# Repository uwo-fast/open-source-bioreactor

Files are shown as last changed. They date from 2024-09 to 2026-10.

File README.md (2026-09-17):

# open-source-bioreactor

Composable, modular, and extensible bioreactor design.

## status

> Under development, not yet ready for use.

- `scad/` - the OpenSCAD source, built around registered parameter sets for purchased parts and composable modules for printed ones. This replaced an earlier iteration that became unwieldy as the assembly grew; that tree was removed in `376c21f` and remains in the history.

## Documentation

- [`docs/build.md`](docs/build.md) — what to cut, print and tighten, and in what order
- [`docs/architecture.md`](docs/architecture.md) — who may hand a number to whom
- [`docs/design-conventions.md`](docs/design-conventions.md) — the rules the model is built to
- [`docs/agitation.md`](docs/agitation.md) — why the impeller is the size it is
- [`docs/ports-layout.md`](docs/ports-layout.md) — what sits at each port on the lid, and why
- [`docs/procurement.md`](docs/procurement.md) — how the bought parts were chosen
- [`docs/references.md`](docs/references.md) — the sources, and how far each one was actually read

## OpenSCAD Libraries

- [github.com/CameronBrooks11/bayonet-lock-scad](https://github.com/CameronBrooks11/bayonet-lock-scad)
- [github.com/thehans/FunctionalOpenSCAD](https://github.com/thehans/FunctionalOpenSCAD)
- [github.com/nophead/NopSCADlib](https://github.com/nophead/NopSCADlib)
- [github.com/rcolyer/threads-scad](https://github.com/rcolyer/threads-scad)

---

<div align="center">
  <p>
    
    
  </p>
</div>

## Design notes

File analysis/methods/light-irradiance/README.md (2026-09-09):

# Light irradiance — LED vs fluorescent

Spectrometer characterisation of the two lighting options considered for the
reactor, measured 2025-01. This is a **method**, not a culture run: it
characterises hardware and can be re-run against any future light source.

## Files

| Path | What |
| --- | --- |
| `raw/spectroscopy_data.csv` | Spectrometer export, untouched. Seven trials, 3,648 samples each. |
| `pipeline.py` | Rebuilds the per-condition splits and all four plots. |
| `derived/` | Regenerated, git-ignored. |
| `figures/` | Committed plots. |

Rebuild with:

```bash
just analysis-method light-irradiance    # or: python pipeline.py --verify
```

## Conditions

The raw export carries seven `(wavelength, irradiance)` column pairs under a
merged header row that names three conditions:

| Condition | Trials | Split file |
| --- | --- | --- |
| LED at 1 cm | 1 | `derived/spectroscopy_led1cm.csv` |
| Fluorescent, peak matched to the LED at 90 µW/cm²/nm | 3 | `derived/spectroscopy_flor90uWpeak.csv` |
| Fluorescent at 1 cm | 3 | `derived/spectroscopy_flor1cm.csv` |

Those three split files used to be committed as hand-made copies with no
script behind them. They are now regenerated: select the condition's columns,
then drop negative irradiance to NaN. Negative readings are instrument noise
below the detection floor — 363, 2,398 and 2,188 samples respectively, which
`--verify` reports.

Plots cover 300–800 nm, the range that matters for photosynthetically active
radiation.

## Reload

```python
import pandas as pd
led = pd.read_csv("derived/spectroscopy_led1cm.csv")
```

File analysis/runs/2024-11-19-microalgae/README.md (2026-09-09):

# Microalgae run — 2024-11-19

The first instrumented culture run on the v1 bioreactor. Temperature,
dissolved oxygen and pH were logged alongside the stirring motor and sample
pump for 8.9 days (2024-11-19 19:06 UTC → 2024-11-28 16:23 UTC).

This run predates the anolis telemetry stack; see
[`../2026-07-23-chlorella-ccpc90/`](../2026-07-23-chlorella-ccpc90/) for the
current export format.

> **Provenance warning.** Organism, strain, medium and vessel were never
> recorded for this run, and cannot now be recovered. Treat it as a
> commissioning shakedown of the logging chain rather than a characterised
> culture experiment.

## Files

| Path | What |
| --- | --- |
| `raw/microalgae_raw.csv` | The logger export, untouched. 28 MB, 152,712 rows. |
| `pipeline.py` | Rebuilds everything below from the raw file. |
| `derived/` | Regenerated, git-ignored. |
| `figures/` | Committed plots. |

Rebuild with:

```bash
just analysis-run 2024-11-19-microalgae     # or: python pipeline.py --verify
```

## Raw format: paired channels, independent clocks

The raw CSV is **not** a table. It is fourteen independent channels laid
side by side, each a `(time, value)` column pair with its **own clock and its
own length**, space-padded to the longest:

```
time,Air Cal,time,DO Cal,…,time,Thermo 1,time,Dissolved Oxygen,time,pH,time,Stirring,time,Pump 1,…
```

Row _i_ of `Thermo 1` and row _i_ of `pH` are **unrelated samples**. Channel
lengths differ accordingly:

| Channel | Samples | Kept as |
| --- | --- | --- |
| `Thermo 1` | 152,615 | `temperature` |
| `Dissolved Oxygen` | 152,624 | `dissolved oxygen` |
| `pH` | 152,661 | `pH` |
| `Stirring` | 152,688 | `stirring motor` |
| `Pump 1` | 152,712 | `sample pump` |

The other nine channels are one-shot calibration events (2 samples each) plus
the unused heating element and pH-control outputs, and are dropped.

## ⚠ The historical pipeline misaligned the channels

The originally committed `cleaned0/1/2` files were built by stacking the
channels **by row position**, which silently pairs samples taken minutes
apart. Measured skew relative to the `Thermo 1` clock:

| Channel | Median | 95th pct | Worst  |
| --- | --- | --- | --- |
| Dissolved Oxygen | −39 s  | +0.6 s | −475 s |
| pH | −154 s | −3.5 s | −513 s |
| Stirring | −258 s | −43 s | +948 s |
| Pump 1 | −338 s | −28 s | +948 s |

So in every previously published figure from this run, **pH lags its stated
timestamp by ~2.5 minutes on average and actuator state by ~5 minutes**, with
excursions to ±16 minutes. Slow trends are unaffected; anything that reads
short-term cause and effect between an actuator and a sensor is not.

`pipeline.py` therefore emits two frames:

- **`derived/tidy.csv`** — correct. Channels aligned onto the `Thermo 1` clock
  with a backward as-of join and a 30 s tolerance, so gaps stay NaN rather
  than being carried forward. **Use this.**
- **`derived/legacy_cleaned{0,1,2}.csv`** — bit-for-bit reconstructions of the
  files that used to be committed here, kept only so past figures remain
  auditable. Do not build new analysis on them.

Both apply the same two physical filters the original scripts did: temperature
outside 20–45 °C is sensor noise (there was no active heating or cooling), and
pH below 7 is the probe still settling at the start of the run.

## Reconstruction provenance

The step from `raw` to `cleaned0` was originally done by hand in a spreadsheet
and **no script for it was ever committed**. It has since been reverse-
engineered and is now `align_by_row_index()` in [`pipeline.py`](pipeline.py):
take channels by raw row position, set `time = round(Thermo 1 time)`, drop the
duplicated first scan, drop the final row, and uppercase the booleans.

`python pipeline.py --verify` checks the reconstruction against the sha256 of
each file as it was committed before the 2026-08 restructure:

| File | sha256 | Status |
| --- | --- | --- |
| `legacy_cleaned1.csv` | `0d2900e5…` | byte-identical |
| `legacy_cleaned2.csv` | `91ff8a32…` | byte-identical |
| `legacy_cleaned0.csv` | `b158e353…` | see below |

`cleaned0` as committed had sha256 `e64c807c…` and differs from the
reconstruction in **exactly one cell of 915,678**: the spreadsheet rounded a
temperature reading of `4.37069000783219e-19` to `4.37E-19`. The digest
recorded in `pipeline.py` is the faithful unrounded value. Nothing downstream
is affected — that sample fails the 20–45 °C filter either way, which is why
`cleaned1` and `cleaned2`, the files every published figure was actually built
from, still reproduce exactly.

## Reload

```python
import pandas as pd
tidy = pd.read_csv("derived/tidy.csv", parse_dates=["datetime"])
```

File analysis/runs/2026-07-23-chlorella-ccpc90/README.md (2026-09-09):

# Chlorella vulgaris (CCPC 90) photobioreactor run — telemetry export (2026-07)

Full telemetry export of the July 2026 bioreactor culture, pulled from the Pi's
InfluxDB just before the culture was evacuated and the bench sterilized.

## Culture

- **Organism:** _Chlorella vulgaris_, strain **CCPC 90**
- **Feed / medium:** 0.2 g/L Miracle-Gro in DI water (unbuffered)
- **Control:** impeller stirring only; **no active pH control** (dose pumps configured but disabled the entire run)
- **Vessel / stack:** bioreactor-v1 machine profile; anolis runtime `bioreactor-automation`, providers `bread0` (CRUMBS/I2C actuators) + `ezo0` (Atlas EZO pH/DO probes)

## Export provenance

- **Source:** Pi `anolis-f95d50b1` (129.100.228.70), InfluxDB org/bucket `anolis` (native `--with-observability`, 30-day retention)
- **Window:** `2026-07-23T02:10:05Z → 2026-07-31T18:05:05Z` (~8.7 days, full retained history of this culture)
- **Exported:** 2026-07-31 (~14:05 EDT) via **`anolis-telemetry-export` v0.1.1** (`POST /v1/exports/signals:query`, `resolution.mode=raw_event`, `format=csv`), run from source on the Pi.
- All timestamps are **UTC (RFC3339 Z)**. EDT = UTC−4.
- Per-export manifests (query params + sha256 content hash) are in `raw/manifests/`; `raw/export_index.tsv` maps each signal → export-id → manifest-hash → row count.

### Why per-`(device,signal)` queries (tool caveat)

`anolis-telemetry-export` v0.1.1 has two bugs in `raw_event` mode when a query
spans **multiple field types** (`value_double`/`value_int`/`value_bool`/`value_string`/`value_uint`):

1. **Leaked header rows** — a fresh CSV/NDJSON header is re-emitted at every field-type transition (≈17 junk rows per 15 min of mixed data). Present in **both** CSV and NDJSON (upstream of the formatter).
2. **Wrong `value_type`** — every row is labelled `bool` regardless of the real type.

**Workaround used here:** query one `(device_id, signal_id)` pair at a time — each is a single field type → a single Flux table → **0 leaked headers and correct `value_type`**, at full raw fidelity. Verified: 0 leaked header rows across all 29 files; each signal carries exactly one correct type. `downsampled` mode is also clean (single pivoted table) if a smaller file is ever wanted.

## Files

| Path | What |
| --- | --- |
| `raw/signals_raw_long.csv` | **Master dataset** — all 29 signals, raw events, time-sorted, long/tidy format. 587,061 rows. |
| `raw/manifests/<device>__<signal>.manifest.json` | Export manifest per signal (query window, selector, row count, content hash). |
| `raw/export_index.tsv` | device · signal · rows · leaked_hdr(=0) · export_id · manifest_hash. |
| `pipeline.py` | Rebuilds everything below from the master. |
| `derived/per_signal/<device>__<signal>.csv` | The master split one file per signal (handy for loading a single series). Git-ignored. |
| `derived/pivoted_1min.csv` | Sensors resampled onto a shared 1-minute grid. Git-ignored. |
| `figures/` | Committed plots. |

`per_signal/` used to be committed next to the master, which stored all
587,061 rows twice. It is now regenerated:

```bash
just analysis-run 2026-07-23-chlorella-ccpc90    # or: python pipeline.py --verify
```

`--verify` cross-checks every regenerated split against the row counts in
`raw/export_index.tsv`; the splits come back byte-identical to the original
export.

### Schema (`raw/signals_raw_long.csv`)

```
timestamp,runtime_name,provider_id,device_id,signal_id,value,value_type,quality
```

Long format: one row per observed change (telemetry is emitted **on change**, not
at a fixed rate), so sampling cadence varies by signal. To analyze, pivot on
`timestamp` × `signal_id` (values don't share exact timestamps across signals —
resample/`merge_asof` in pandas).

### Signal glossary

| signal_id | device | meaning | type |
| --- | --- | --- | --- |
| `ph_value` | ph0 | pH | double |
| `do_mg_l` | do0 | dissolved O₂ (mg/L) | double |
| `do_saturation_pct` | do0 | dissolved O₂ (% sat) | double |
| `t1_c` | rlht0 | reactor temperature (°C) | double |
| `t2_c`, `setpoint1_c`, `setpoint2_c` | rlht0 | secondary temp / heater setpoints (unused this run) | double |
| `relay1_on`, `relay2_on` | rlht0 | heater relays (unused) | bool |
| `period1_ms`, `period2_ms` | rlht0 | relay PWM periods | uint64 |
| `motor2_target` / `motor2_value` | **dcmt0** | **impeller** commanded / echoed PWM (0–255) | int64  |
| `motor1_*` | dcmt0 | dcmt0 channel-1 (sampling; unused) | — |
| `motor*_*` | **dcmt1** | **dose pumps** (disabled entire run → flat) | — |
| `motor*_brake`, `estop` | dcmt0/dcmt1 | brake / e-stop state | bool |
| `mode` | dcmt0/dcmt1/rlht0 | device control mode (`open_loop` etc.) | string |

Row counts (raw events over the window): `ph_value` 204,189 · `t1_c` 181,988 ·
`do_saturation_pct` 97,898 · `do_mg_l` 91,316 · impeller `motor2_*` (dcmt0) ~764 ·
dose/other actuator + rlht static signals 204–755 each.

## Run timeline & caveats (read before analysis)

Full ops/dev detail: `anolis/working/incident-2026-07-24-impeller-failure.md`.

- **Impeller (dcmt0) failed 2026-07-23 19:46 EDT**, undetected ~22 h; recovered 07-24 ~20:19 EDT (board power-cycle + staged restart). No stirring/dosing in that gap → pH fell to ~3.9.
- **Base dose(s)** added manually (unbuffered medium, no pH-stat) → pH stepped back up; culture ran at pH ~8.3 thereafter.
- Two **unexplained reboots** (07-24 11:45, 07-28 23:14 EDT) — brief telemetry gaps.
- **Planned power outage 2026-07-30 18:00 → 07-31 ~06:15 EDT (~12 h):** hard power-off, ~12 h gap in the data. Over the dark/unstirred window the culture **respired** (DO 140 %→86 % sat, pH 8.12→~7.5). **⚠ Clock artifact:** the Pi has no RTC battery, so a short burst of post-boot IDLE data around 07-31 morning is mis-stamped **~22:00–23:00 UTC 2026-07-30** (fake-hwclock restored the poweroff time until NTP synced ~11:00 UTC). Treat the true run boundary as the power cut ~22:00 UTC 07-30 (18:00 EDT).
- Final **short stirred run** 07-31 ~17:22 EDT to capture recovery, then culture evacuated.
- **DO probe** reads supersaturated (>100 % sat) for most of the run — active photosynthesis, but calibration date unknown; treat absolute DO with caution, trends are reliable.

## Reload

```python
import pandas as pd
df = pd.read_csv("raw/signals_raw_long.csv", parse_dates=["timestamp"])
ph  = df[df.signal_id=="ph_value"][["timestamp","value"]]
do  = df[df.signal_id=="do_saturation_pct"][["timestamp","value"]]
tmp = df[df.signal_id=="t1_c"][["timestamp","value"]]
```

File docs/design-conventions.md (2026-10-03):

# Design conventions

Rules this model is built to. They were arrived at by getting them wrong first, so each one carries
the failure it exists to prevent. Anything contradicting them is a defect rather than a variation.

---

## The rim datum

**The lid is located by the glass rim.** Its gasket seats on the top of the glass and its plug
enters the mouth. The rim is fixed by the jar; the frame's top base is derived _below_ it.

**What the gasket seats ON is per jar, and only one of them is flat.** `jar_6p5gal_305x470` is
ground and presents a flat annulus. Every other jar is fire-polished and presents a CROWN — the
glass rolls over, and on two of them the roll stands proud of the wall as a bead. So there is no
land to inset a gasket into and none to bottom the flange on: the gasket covers the lip instead,
and what gets squeezed is the band the crown makes as it sinks in.

The consequence that matters: the **2.4 mm gap** between the top base's upper face and the lid
flange's underside is _required_, not slack to be removed. It is the clearance that lets the joint
bolts pull the lid down **into** the vessel rather than bottoming it on the frame. Every span
crossing the joint has to count it — bolt grips, nut placements, anything measured from one side to
the other.

Anything that seats the lid on the frame instead of the glass is wrong. This was mis-derived
backwards twice before it was written down.

**Frame coordinates.** The frame builds with z = 0 at its own floor, then draws its body offset by
`−base_floor_height`. Frame-local `total_height` = 349.75 is assembly z = 305, the rim. If those
look contradictory, the offset has been forgotten.

---

## One physical thing, one expression

The repo's recurring defect: one physical fact stated twice, in two places, which agree until one
moves. Every instance found this way was silent — the model built happily and the two numbers
simply diverged.

Real examples, each of which shipped:

- The **strip light** was selected twice — the assembly passed only its length while the frame read
  its own second selection. Changing the light resized the frame around a pocket that never moved.
- The **impeller ratio** multiplied the vessel's outer diameter where D/T means the bore, so the
  real ratio drifted with glass thickness rather than being held constant.
- The **cart** sized its envelope off the bare jar, so two bioreactors on a tier overlapped by
  17.4 mm and each passed through the rail above it.
- The **bearing's** allowance was applied twice — once folded into the registered diameter and again
  as the pocket allowance — leaving the pocket 0.8 mm oversize.
- The **eccentricity analysis** measured T as the outer diameter — the impeller-ratio defect above,
  recurring in a document after it had been fixed in the model, so the two disagreed about what T
  meant while sitting in one repository. Nothing could catch it: no geometry reads those numbers.
  It is the clearest case for the rule below that a document is the second expression, and the
  worse place for one.

The fix is always the same shape: one expression, read back by whoever needs it. Subassemblies
export accessors (`frame_outer_diameter()`, `head_gasket_factor()`) rather than have consumers
rebuild the value.

**Name the quantity, not a quantity that resembles it.** Three defects here came from names that
permitted two readings — outer diameter versus bore, motor speed versus output speed, screw centre
distance versus bolt circle. If a field could be read two ways, it eventually will be.

**Documents are the second expression.** The same defect appears in prose, and there it is worse:
the model cannot check a document, so a stale figure sits unchallenged until a reader trusts it.
Eight were found in one pass — a D/T cap the model had moved, a thermocouple nothing buys, a pump
delivery the model explicitly retracts in its own echo, a fenced echo quoting a number the model no
longer emits, and one document stating both that the baffle hangs its full length and that it has
never been lengthened.

Prefer quoting an accessor or an echo over restating its result. Where a figure must be written out,
**check it against the model rather than against another document** — several of these agreed with
each other and with nothing else.

**A corrected figure is replaced where it sits and recorded once in `decisions.md`.** The old
value is evidence of which assumption failed, so it goes under _Corrections_ there, with what made
it wrong. It does not stay inline: a superseded paragraph beside its replacement is a second
expression of the same fact, and the commit that made the correction already holds the diff.

---

## Three layers, and where a parameter lives

The model was built on two: things two components must agree on, which live in `bioreactor.scad`, and
a component's own preferences, which live in its own file. That is right as far as it goes, and it
misses a third kind, which surfaced when a build's choices had nowhere to be stated.

A **DESIGNATION** is a per-reactor choice: which registered jar, which motor, which probe in which
port, what fill fraction. It is not a preference — it is about _this_ build, not about the design —
and it is not classic coupling, because `bioreactor.scad` may never consume it. It is forced into the
entry file anyway, by a platform fact: a customizer parameter set can only assign parameters
declared in the file being rendered. See _What the customizer can and cannot carry_.

**Where a parameter lives.** It belongs in `bioreactor.scad` if any of these hold:

- two or more components must agree on it;
- `bioreactor.scad` itself consumes it in a derivation — `frame_wall_thickness` feeding
  `joint_outer_diameter`, the fill fraction feeding light selection, the shaft feeding the envelope;
- it is a designation, a per-reactor choice an operator states.

Everything else stays in the component that embodies it: allowances, wall thicknesses, land margins,
joint geometry, and the search that derives a designation left unstated.

**A designation travels as a NAME, never as a row.** A parameter set holds values, not references,
so a registered row cannot be named directly. The form is a string parameter resolved through that
registry's by-name lookup — `reactor_vessel_name` with `vessel_by_name()` is the pattern — with a
loud assert on a name nothing matches. `"auto"` means _derive it_.

That string is not the plausible number this document bans elsewhere. `undef` is unavailable here
(the customizer cannot see it) and a numeric sentinel would be exactly the plausible value that
propagates unnoticed into arithmetic. A string cannot: it is visible in the surface, it is carried,
and it is consumed by a mode branch that never multiplies it by anything.

**Only departures travel.** The build list packs only what a build actually states; anything left at
`"auto"` is omitted, so the component's own search remains the single expression of the default.
Nothing is ever declared live in two files with defaults kept in step by hand.

**A value read back out of a component is an argument whose default is that component's own.**
`function head_gasket_factor(sheet = lid_gasket_sheet)` — verified: a default argument resolves in
the file that defines the function, not the caller's, so one expression serves both the standalone
preview and the assembled build and the readback cannot disagree with the geometry it describes.

**Pinning does not switch the checks off, it inverts them.** A designated row runs the same fit
asserts the derived one would have, and the echo reports what was pinned _and what derivation would
have chosen_. A selection over a registry holding one row says so — "sole registered row,
fit-checked, not chosen" — rather than implying a choice was made.

---

## Purchased parts are registered rows that drive geometry

Every bought part is a row in `scad/purchased/`, and the geometry is cut from the row rather than
from numbers typed beside it. The hole is derived from the insert; the pocket from the bearing; the
gasket recess from the sheet's thickness.

The failure this prevents: a heat-set insert was once modelled from a library row that **was not a
purchasable part**, and the lid was printed for it. A registry row must describe something orderable,
and where a library already carries the real part (`BB608` is the 608 bearing actually bought) the
library row is used directly rather than copied.

**The contract every registry owes.** A rows list; a `*_name()` accessor; a part number where a
stable one exists, and `undef` with the reason where it does not; provenance travelling with each
value; and a `*_by_name()` lookup wherever the part is designatable. Data-only registries — rows
that carry numbers and draw nothing — are legitimate.

**Only REAL parts go in the swept list.** The list is what `check-echo` and the sweeps build
against, so what sits in it is a claim about hardware.

A **placeholder** — a row describing nothing anyone ever bought, like `generic_vessel` or a
`"generic"` probe with an empty part number — stays defined and out of the list. It is a shape, not
a product, and sweeping it makes "this builds" cover something nobody can buy.

A **discontinued or bundled** part is the opposite case and stays swept, with the deviation recorded
beside the list. The 36GP motor is no longer sold and is on the bench; the 12 V pump motor arrives
fitted to a pump head and has no part number of its own; both Atlas g1 probes are out of production
and still in use. Refusing to sweep those would stop checking hardware that exists, which is the
wrong way round — the point of the sweep is that real parts build.

**Designatable is not the same as purchased.** Every bought thing is a registered row; only the ones
an operator actually picks per reactor get a by-name lookup and a slot on the build surface. The
bearing, the heat-set inserts, the screws, the riser tube and its o-ring, the hose clamp are the
design's bill of materials — one expression each, not a menu.

---

## A number is a claim, and it carries how good a claim it is

Parametric CAD makes numbers adjustable. It does not make them _true_, and adjustable-but-unfounded
is the more dangerous state, because the model looks equally confident either way.

So every quantity in this model is one of four kinds, and which kind it is travels with it:

- **measured** — a source states it for this exact thing. `impeller_rushton_6`'s `Po 4.17 ± 0.14`.
- **correlated** — a published correlation computes it from this geometry, and can say where that
  geometry leaves the correlation's validity. `pbt_45_4` takes `Po` from Medek this way.
- **borrowed** — no source reaches this shape, so a nearby one's number stands in. Always echoed,
  never silent.
- **reasoned, not cited** — nothing in the literature held here supports it and the model needs a
  value anyway. Marked in the source with that exact phrase: the 0.5 D coverage floor, the baffle
  load, the mount slenderness limits, a diaphragm pump's curve taken as linear.

The failure this prevents is a borrowed number acquiring the authority of a measured one by sitting
in the same table. This model ran for months on `Po = 0.99` borrowed from a differently shaped
blade, annotated _conservative_; when the correlated value arrived it was **1.602**, so every power,
torque and dissipation figure had been 62 % optimistic while carrying a note saying the opposite.

**A registry row states what a source says, not what the design wants.** Where a source gives a
band, register the band. Where it gives nothing, register `undef` rather than a plausible number —
`undef` propagates and gets noticed, a plausible number does not.

---

## Report the departure, not just the number

Every correlation has a validity envelope, and this vessel is outside several of them. That is
normal for an instrument built from jars rather than from a vendor's catalogue. What is not
acceptable is _not knowing_ which ones.

So a check returns the **names** of what it violates, not a boolean:

```
impeller: pbt_45_4 Po 1.49248 and flow number 0.887217 from Medek's correlation
at 45 deg, extrapolated on ["T/D", "H/T"]
```

`stirred_tank_medek_departures()` returns a list because an extrapolation that is out on one count
is a different thing from one that is out on four, and a caller that only learns `false` cannot tell
them apart or say which to fix. Two of those three departures were removable — a fourth baffle
retired one, D/T would retire another — and that was only visible because they were named.

The same shape applies to bands the design is measured against: echo the value, the band, and the
source's own framing. Oldshue's `1–2 d` is an **allowance** — _"if the impeller can be placed…
these impellers offer"_ — so falling outside it is reported, not warned. And it is an allowance for
**fluidfoil** impellers, which this pitched blade is not, so the model says that too rather than
quietly grading one impeller class against another's guidance.

---

## Report a fit before you build the part

Register the geometry and its clearances, render, and read them — then draw. The reporting is
cheaper than the part and it is what catches the arithmetic.

The case that made this a rule: a sparge ring was planned at 1.4 D with **1.60 mm** of clearance to
the baffles. That figure was ring _centreline_ to baffle edge; the ring has a 6 mm section, so its
inner face is 3 mm further in and the true clearance is **−1.40 mm**. The ring overlapped. Nothing
about the plan looked wrong — the number was plausible, stated with a unit, and derived from real
dimensions. The assert caught it on the first render, before any geometry existed.

Working it properly then changed the design rather than the number: the radial band available is
6.95 mm, no round section of 6 mm fits it at any diameter, and the squeeze is entirely radial while
73 mm of height sits unused. The ring's section became 4 × 10 mm, which is also the reason it is
printed rather than bent — **a tube is round, and round does not fit**.

The 4 × 10 section was itself overtaken by a requirement the fit report could not see — a sealed
slot cannot be cleaned — and the sparger is a round tube now, placed by the mouth; see
`decisions.md`. The lesson stands: the fit report is what caught the −1.40 mm.

A model whose checks only run after the geometry exists will confirm whatever was built.

---

## The model should be able to catch its author

The point of the three sections above is not documentation. It is that the model disagrees with the
person editing it, in the same session, before anything is committed.

Every one of these was found by a check rather than by re-reading:

- `head()`'s `z = 0` is the lid's **outer** face, which the assembly seats `lid_flange_height` above
  the rim — so every vessel-referenced depth was **8 mm** out, and the drivetrain was drawn higher
  than the model reported it.
- The baffle area ratio compared plate **width** against a reference **area**, reporting 0.83 for
  baffling that was actually at 0.14.
- Medek's four-baffle condition was evaluated against `len(undef)`, because `_baffle_at` was
  assigned 230 lines below its first consumer — so it reported a departure on a lid that has four.
- A pitched blade run out to `radius` sweeps **past** the diameter its power number is defined on,
  because a tilted rectangle's outermost points are its corners. 1.5 % on diameter is 7 % on power.
- A round feed boss on the sparge ring was wider than the ring's own section and fouled the baffles
  and the jar's mouth simultaneously, at 0.29 and 0.26 mm.

None of these were subtle once seen and none were visible while writing the code that caused them.

**What this costs.** It is verbose, and it is only as good as the checks someone bothered to write —
a number can be wrong in a way nothing checks, and a reported band is not a promise the value is
right. `reasoned, not cited` is still a guess; it is only a _labelled_ guess. The claim here is
narrow: that labelling which numbers are weak, and naming which conditions are violated, converts a
class of silent drift into a line of render output.

---

## Asserts versus echoes

This reactor is a research instrument. A parameter outside the usual range may be exactly what
someone is studying, so the model reports rather than refuses.

- **Assert** only what is physically impossible or unbuildable — an impeller too wide to pass the
  vessel mouth, a pocket cut through into the culture, a nut deeper than the base it sits in.
- **And cited bands at the pressure boundary may assert**, which is a deliberate exception rather
  than a lapse. The three o-ring checks — riser stretch, plug gland fill, plug containment — guard
  the seal between the culture and the room, and they come from gland practice rather than from
  this project's judgement. A seal outside its band is nearer unbuildable than it is to a variation
  someone is studying. A limit that is `reasoned, not cited` does **not** get that authority: it
  echoes.
- **Echo** the value and the literature band it sits against, with a distinct warning line when it
  falls outside. The build continues.

### Dead versus weak asserts

- **Dead** — the expression cannot vary, so no input reaches the failure. Delete it; it reads as
  coverage while providing none.
- **Weak** — it varies, but only absurd inputs trip it. Cheap insurance, keep it.

**Deadness is tested by sweeping the assert's own driving parameter**, never a proxy. Sweeping the
vessel registry proves nothing about a guard driven by cord diameter. Two asserts were deleted this
way after proving algebraically that their terms cancel; one more was very nearly deleted on a
proxy sweep before the correct driver showed it firing.

An assert derived from the thing it checks can never fire. If the code just computed the
relationship, do not then assert it.

---

## Verifying a change

Two OpenSCAD behaviours govern how anything here is checked, and both are counter-intuitive:

**A failing assert still exits 0.** A failed CSG export returns success and writes a ~1 byte file.
Nothing may be gated on `$?` — `just check-scad` greps stderr for `ERROR` and uses file size as a
backstop. Before this was understood, every failing vessel in a six-vessel sweep looked like a pass.

**Mesh export is not reproducible; CSG export is.** The same file exported three times gave 29454,
29452 and 29456 facets at three different file sizes, while the distinct z-level set and the
bounding box were identical across all three and the CSG output hashed identically.

So:

- _valid_ evidence — CSG diffs, distinct z-levels, bounding boxes, per-feature coordinates
- _not evidence_ — facet counts, STL file size, STL hashes

This also rules out STL hashing as a regression check for any future export tooling.

**A CSG diff is blind to whatever the preview drops.** `head.scad` sets
`$bayonet_shell_only = $preview && fast_bayonet_preview`, which makes the bayonet library emit bare
shells and skip every pin, channel and notch. CSG export runs in preview, so a CSG comparison shows
those features as unchanged **whatever was done to them** — a change to the pin angles came back
byte-identical, twice, before this was understood.

So a CSG diff proves nothing about a feature the preview is suppressing. Either render the affected
part on its own, or pass `-D fast_bayonet_preview=false` and compare that. The general form: **check
what the flags were before trusting what the diff says**, because a diff of two things that were
never drawn is a clean diff.

**`WARNING` is evidence too.** OpenSCAD reports an undef reaching arithmetic as a warning, not an
error, and a parse error in a `use`d file shows up as nothing else at all — a missing comma between
two string literals silently stopped `head.scad` exporting any of its functions while the file still
rendered on its own, and ninety warnings rode along unnoticed because the gate only grepped `ERROR`.
`check-scad` now fails on either.

**`just check-scad`** evaluates every file in both directions: the ones meant to render standalone
must emit geometry, and every other file must emit **none** — a registry that draws its own example
draws it into every consumer, which has happened once already. A new entry file therefore fails
until it is listed, which is the point.

**Neither of those runs CGAL, so neither can see a broken solid.** `.csg` export is a dump of the
tree, not an evaluation of it, and a mesh export tessellates without being asked whether the result
closes. The impeller's blades were drawn TANGENT to the hub — 264 non-manifold edges — and every
check above passed on it, every render, every time. It was found by measuring the STL.
**`just check-mesh`** closes that: it renders to a mesh and fails on a defect count above zero, and
**`just export-parts`** applies the same test to every part on the print manifest, one at a time.

**A check must be run in the configuration that makes the part, not the one that makes the
picture.** Four entry files render an assembly by default, and `check-mesh` used to skip all four as
"slow" and invite you to run them before a print. Three of them cannot pass: `head.scad`'s printed
geometry alone IS a 2-manifold, and what breaks it is `render_seals`, `render_probes`, and the
bearing with its coupling — EPDM in its grooves, Atlas bodies in their collets, a bearing on the
shaft, every one of them already on `check-parts`' `not_printed` list. So the check failed on
vitamins the repo had declared are not printed, could never pass, and taught anyone who ran it to
ignore it. `support/electronics_stand.scad` was on that list too and is not even slow: 14 s as a picture,
and 4 s as the bracket it prints, which is a clean 2-manifold. It is checked now.

**A check that cannot pass is worse than no check**, because the next real failure reads as more of
the same noise.

**Check at the `$fn` the desk uses, not only the one CI pins.** `$fn` is dynamically scoped, and
2021.01 lets a `use`d module resolve it from its own file where newer builds pass the caller's — so
a module that divides by `$fn` is fine under one and produces `nan` under the other. Nobody sees it,
because a `nan` propagates into a comparison that is simply false. `check-scad` runs a second pass at
**`-D '$fn=0'`**, which is what an unset viewport actually is, and geometry derives its facet count
from `$fa`/`$fs` rather than reading `$fn` off the caller.

**A clash check on a stand-in shape proves only the stand-in.** The condenser coil's preview tube was
a horizontal disc swept round the helix, a 0.4 mm ribbon in section, and a collision test passed on
it that a round tube would have failed; the printed head then cracked where the real tube would not
bend. Draw what is checked from the part's real section, and prove the check can fail by moving the
thing it guards - half a pitch, a few degrees - and watching it report. And a fit is not the only
question for something bent or wound: it has to be formable, at a radius the material takes, in the
order the parts go together - and a part it is formed against has to be built to carry that, which
the head that cracked was not, since its job was to locate a finished coil.

---

## What the customizer can and cannot carry

Measured on **OpenSCAD 2021.01**, by rendering probes rather than by reading documentation. Every
rule in _Three layers_ rests on these, so a version bump re-runs them before anything else.

- **`-D` reaches a `use`d file's globals. `-p`/`-P` does not.** A parameter set assigns only
  parameters declared in the file being rendered; keys naming a `use`d file's globals do nothing,
  silently. This is the fact that forces designations into the entry file.
- **A parameter defaulting to `undef` is invisible to the customizer.** It has no inferable type, so
  no parameter set can assign it. Proved by giving one a numeric default, at which point the same
  set applied. This is why a designation defaults to `"auto"` and never to `undef`.
- **A flat vector is carryable, but only as a string holding a SCAD literal.** A native JSON array
  is ignored without warning; `"[\"x\",\"y\"]"` applies, and may change length. Anything
  generating a parameter set has to emit that form.
- **A nested table cannot be carried at all**, in either encoding. Port tables and registry rows
  stay in SCAD; only their names travel.
- **`-p` beats `-D` on the same key, silently.** Keep the two key sets disjoint.
- **Almost everything fails at exit 0** — a bad `-P` name, a missing file, an unknown key, an
  unparseable value. Detection is a stderr grep or a `jq` check, never `$?`.
- **`-o /dev/null` does not render at all** — it exits 1 on the missing suffix. A check written that
  way passes whatever it is pointed at, which is the shape of check this document warns about
  everywhere else. Export to a real file.
- **Dropdown annotations are comments**, so an option list cannot be generated at runtime. Where one
  mirrors a registry, both ends say so.

---

## Standalone previews

Each subassembly renders on its own. Those previews must **derive** what the assembly would hand
them rather than quote the resulting numbers — a preview that quotes a bolt circle keeps building
the old one after the real derivation moves, and a part exported from it will not fit.

What a preview may legitimately choose are the things the assembly chooses: the vessel, the light,
the wall thickness, the flange height. Everything downstream of those is derived.

**A subassembly keeps its own parameters as live standalone defaults.** Opening `head.scad` and
working on it directly is worth more than the purity of deleting them, and an assembled build
overrides them only through the departures it states. Where a preview must restate something the
assembly owns, the restatement carries the drift label — it is two expressions held in step by
discipline and by the echo, not by construction, and it should be visible as such rather than
quietly correct.

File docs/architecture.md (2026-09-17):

# Architecture

Where a number is allowed to come from. `design-conventions.md` says how a number is justified;
this says who may hand it to whom. It is normative: a file that breaks a rule here is a defect, and
the audit of which files do is in `TODO.md`, not here.

## The layers

```
bioreactor.scad        the build: designations resolved, coupling derived once, head + frame composed
  ├── head.scad        subassembly: takes its coupling as arguments, standalone defaults
  ├── frame.scad       subassembly, same contract
  │     ├── custom/    printed parts: arguments in, geometry out
  │     ├── purchased/ bought parts: registry rows, accessors, a drawing of the vitamin
  │     └── utils/     standards and laws: thread tables, gland ratios, physics, geometry helpers
support/               furniture around the reactor; may compose bioreactor.scad, nothing composes it
_shelf/  _archive/      off the tree; nothing on it imports them
```

| Layer | Holds | May import | May not |
| --- | --- | --- | --- |
| `bioreactor` | designations by name, the coupling, the composition | `use` head, frame; the registries it resolves from | derive a number a subassembly also derives |
| `head`, `frame` | own preferences as live defaults; parts composed | `use` custom, utils; registries, to resolve names | read the other's state; read `bioreactor.scad` |
| `custom` | one general-case part per file; optionally its own interface registry | `use` utils, another custom part; `include` its own registry | read a `purchased/` registry; know a reactor |
| `purchased` | a swept row list, a by-name lookup, accessors, a drawing | `use` its own drawing, utils | know what it is bought for |
| `utils` | a standard, a law, a geometry helper | `use` other utils | know a part |

`use` unless it says `include`. `include` hands over every global of the included file, which is
the coupling this document exists to stop, so it is reserved for a file taking its own data: a
subassembly including the registries it resolves designations from, `bayonet_port.scad` including
`bayonet_interfaces.scad`.

## The rules

1. **Decisions flow down; interfaces are read back.** A module takes what it consumes as an
   argument. A composer may read a subassembly's accessor (`frame_outer_diameter()`,
   `head_gasket_factor()`) rather than rebuild the value. Nobody reads a global another file set,
   and no file reaches into a sibling's state. The one sideways read is `head.scad`'s standalone
   preview using `frame.scad` to derive the joint; it is preview-only and stays.

2. **A designation is resolved where the choice is owned.** `bioreactor.scad` resolves what a build
   states, by name through the registry's `*_by_name()`; a subassembly resolves its own `"auto"`.
   Geometry never browses a registry to decide what it wants. This is why a subassembly may include
   a registry and a part may not: the subassembly is sometimes the file being rendered. A part's
   standalone preview may `use` a registry to pick its example row by name.

3. **Narrowest coherent interface.** A scalar when the consumer reads one physical fact; the row
   when it depends on the part's identity or several of its fields (a port takes the probe row, a
   gasket takes a thickness); an interface record when two halves must agree (`bayonet_interfaces`,
   the head-frame joint). Fields are read through accessors, never by index.

4. **Derive once.** The bolt circle, the joint diameter, the working volume: one expression, in one
   file, handed on. A standalone preview calls the same function; it never quotes the result.

5. **A subassembly's parameters are live standalone defaults.** The build passes only the
   departures it states, as `[key, value]` pairs, so "derive it" stays distinguishable from "not
   stated". `"auto"` is never packed.

6. **A registry row may name another registry's row, inside the registry.** A motor naming its
   gearbox, an interface naming its o-ring: data describing data, resolved once. It is the one
   cross-registry `include` that is honest, and it is not a licence for geometry to do the same.

7. **Analysis and geometry are separate.** Functions derive; a report module echoes and asserts; a
   geometry module draws. A module that draws does not also carry the fit checks of everything it
   draws. Reports are read by people, so a report line is one line: the quantity, the value, the
   band and the source.

8. **Minimal.** Every argument is consumed. Every exported function has a caller. A wrapper that
   forwards its arguments unchanged is deleted. A comment says what a number is and why; what it
   used to be is in git and `decisions.md`.

## Not yet settled

- Whether a subassembly resolving names itself (rule 2) is the right price for rendering
  standalone, or whether every name resolves in the entry file and `head.scad` carries a tiny
  profile of its own. The second removes eighteen includes from `head.scad`.
- How a subassembly splits into files without the pieces reading each other. `head()` is one
  module in three sections - derived, checks, geometry - because a module returns nothing, so the
  checks cannot move out without restating what they check. The next cut is by subsystem, where a
  real boundary shows.

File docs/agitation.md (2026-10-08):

# Agitation design basis

Why the impeller is the size it is, what actually limits agitation in this reactor, and what is
still unknown. Sources are catalogued in [`references.md`](references.md); this document is the
reasoning, not the bibliography.

---

## 1. What limits agitation

Ranked by what the evidence supports:

1. **Bubble rupture at a sparger or free surface** — dominant in any aerated vessel, 10⁷–10⁹ W/m³
2. **Local maximum energy dissipation rate ε_max** near the impeller — not the vessel mean
3. **Shear stress in Pa** — the practical metric for microalgae, measured directly in Couette devices
4. **Kolmogorov microscale against cell diameter** — real principle, not binding at these scales
5. **Tip speed** — a convenient proxy with no mechanistic standing

**Bubble rupture, not impeller shear, is the dominant damage mechanism.** Sobczuk et al. studied
_P. tricornutum_ and _Porphyridium_ on one rig and concluded that mechanical agitation was not the
direct cause of damage — bubbles rupturing at the culture surface were, with the impeller
implicated only as the thing that generated them. Independently, for mammalian cells, removing the
gas–liquid interface leaves growth and viability unaffected at 100–450 rpm, at 600 rpm in a
fully-filled vessel, and at 1500 rpm for hybridomas.

**Tip speed is not a design criterion.** It does not have the dimensions of either shear rate (s⁻¹)
or shear stress (Pa), a point Nienow makes in 2006 and repeats in 2021. The widely-quoted 1.5 m/s
limit traces to a single measurement on human melanoma cells in 5 % serum, generalised into a
universal rule in a paper that two sentences later reports 6 m/s causing no measurable harm to a
hybridoma line. **No tip-speed limit is asserted anywhere in this model, deliberately.**

**For _Chlorella vulgaris_ the relevant figure is an optimum, not a threshold.** Leupold et al.
measured a peak at **1.26 m/s tip speed (0.45 Pa)** — 4.0 % higher photosynthetic activity and 48 %
higher growth against unstirred — with activity falling back to the unstirred control by **2.03 m/s
(0.9 Pa)** and 7–8 % below it by 5.89 m/s. No lethal limit was found at any speed tested. Chlorella
is a rigid-walled green alga, the most shear-tolerant class.

> **Assumption, stated once and carried everywhere below.** Leupold's apparatus is a Gust microcosm
> — 1.75 L, mixed by a **spinning plate with skirt** 5 cm off the bottom — not a stirred tank with
> an impeller. Their tip speed is that plate's rim speed, and the shear it makes lives in a
> plate-to-wall gap rather than an impeller's discharge jet. **Reading 1.26 and 2.03 m/s as impeller
> tip speeds is this project's transfer, not their result.** It is the only _Chlorella_-specific
> agitation measurement available, so the band below is built on it anyway — but every speed, every
> D/T argument and the motor selection itself inherit that assumption. See `docs/references.md` for
> what the paper actually reports, including that its calibration is direct only to 250 rpm and that
> the quoted Pa figures are the stress the authors call secondary in their own experiment.

---

## 2. This reactor, in the units that matter

Computed on the 94.5 mm impeller in the 10 L jar, with **Np = 1.492 from Medek's correlation** for
the registered 45° four-blade pitched turbine, and x = 16. Mean dissipation is over the **8.17 L**
this build derives from `culture_fill_fraction`, not over the full jar — which holds 9.45 L brim
full. `head()` reports the two registered-drive rows; the others are computed from the same
relations at the speeds the Chlorella band asks for.

| shaft speed | tip speed | Re | ε̄ (W/m³) | ε_max (W/kg) |
| --- | --- | --- | --- | --- |
| 255 rpm — Chlorella optimum | 1.26 m/s  | 37,800  | 105 | 15.4 |
| 320 rpm — registered drive, rated | 1.58 m/s  | 47,400  | 208 | 30.4 |
| 410 rpm — break-even | 2.03 m/s  | 60,800  | 437 | 64.1 |
| 420 rpm — registered drive, no-load | 2.08 m/s  | 62,300  | 471 | 68.8 |
| 1154 rpm — 36GP-3530 at full speed  | 5.71 m/s  | 171,100 | 9,770 | 1,429 |

Np comes from this impeller's own geometry by a correlation that states where it is extrapolated,
and it reads **H/T**, so the fill line is part of the power number.

**The vessel is fully turbulent throughout the band.** Every speed above clears both the textbook
Re > 10⁴ threshold and Nienow's stricter 2×10⁴.

**The margin against damage is large.** At the rated 320 rpm the impeller's peak dissipation is
~3.0×10⁴ W/m³ against bubble rupture at 10⁷–10⁹ W/m³ and a CHO lethal range of 10⁶–10⁸ W/m³ — two
to five orders of magnitude. Agitation is not what threatens this culture.

**Aeration dominates the power budget too.** The one peer-reviewed worked example for a microalgal
stirred tank puts aeration at 29.4–49.1 W/m³ against stirring at 0.65–1.30 W/m³.

### The operating point

On the 94.5 mm impeller the band worth aiming at is narrow:

| target | tip speed | shaft speed |
| --- | --- | --- |
| Chlorella growth optimum | 1.26 m/s  | **255 rpm** |
| break-even, stirring stops paying | 2.03 m/s  | **410 rpm** |

**The registered drive is the 36PG-555PM-14-EN**, 14:1, rated 320 rpm and no-load 420 rpm — 1.58 to
2.08 m/s. Of the motors examined it is the only one that reaches the break-even end of the band,
which matters because the comparison between optimum and break-even is one this instrument exists
to make.

It was taken over a 19:1 sibling whose entire rated-to-no-load span, 265–385 rpm, sits inside the
band. That containment is a workaround for having no speed feedback: with nothing measuring the
shaft, where it settles between rated and no-load is set by load, so both ends have to be safe.
**This motor carries a magnetic encoder instead** — 2 channels, 12 PPR at the motor shaft, which
past the 14:1 is 672 quadrature counts per output revolution and resolves about 0.9 rpm over a
100 ms window, against a band 155 rpm wide. Commanding a speed and measuring it beats choosing a
motor that cannot miss.

Torque is not what limits the choice. The impeller pair draws under 0.102 N·m at rated and under
0.175 N·m at no-load against a 0.490 N·m rating — **21 to 36 % of it** — so the shaft runs nearer
the no-load end than the rated one. That is why the registry carries rated torque and `head()`
reports the comparison at each speed: it is the fact that says where an unmeasured shaft settles.

The registries carry output speed, reduction ratio and rated torque, so `head()` computes Re, tip
speed, power, torque and both dissipation figures at render rather than leaving them to be worked
out by hand. **No-load and rated speed are registered separately**: across the ten ratios of the
36PG-3429 table, rated runs 0.68–0.71 of no-load, so treating a catalogue speed as an operating
point overstates it by about half. An unqualified vendor figure is a no-load figure.

The drive it replaces was open-loop PWM at ~39 % duty on a 1154 rpm motor, with the shaft speed
inferred rather than measured and no published operating point anywhere near the band.

---

## 3. Impeller geometry

### Diameter

`impeller_bore_ratio = 0.45`, measured against the vessel's **wetted bore** — the internal diameter,
not the outside of the glass. This matters: multiplying the outer diameter lets the real ratio drift
with wall thickness, which across this project's vessel registry meant 0.468 to 0.489 for one
nominal 0.45.

The value sits mid-band on every source: 0.3–0.5 generally, 0.4–0.5 for axial impellers in cell
culture, 0.44–0.46 as a manufacturer's "most preferred". Above roughly 0.5 an axial impeller loses
its strong axial motion.

**`jar_6p5gal_305x470` is the binding vessel.** Its 137 mm mouth on a 280.8 mm bore caps the ratio
at 0.4879 with the impeller exactly filling the neck; 0.45 leaves 10.64 mm to pass it through. Every
other registered jar tolerates 0.64 to 0.87.

The model asserts that what the impeller sweeps can pass the vessel's opening.

### The helicoid, and why it was abandoned

The blade this project first drew, `impeller_twisted_paddle_4`, is a constant-pitch helicoid:
`linear_extrude(twist=)` is a pitch specifier, so the blade angle β from the plane of rotation
varies with radius, `tan β = P / (2πr)`, running 83° at the hub to 53° at the tip at 55° of twist.
That is steeper than 45° everywhere — a twisted paddle biased toward radial pumping, not the axial
impeller the D/T guidance is written about — and no correlation reaches it: Medek's envelope stops
at 60°, and the twist papers (Patwardhan & Joshi 1999 §3.4.3, Kumaresan & Joshi 2006 §3.1.3.3)
tested at most 20° of twist where this is 30° on their definition. Both find twist lowers Po, so
the 0.99 borrowed from an untwisted folded blade was an over-estimate for the helicoid. Its blade
height has no source either.

The hub was grown from 7.5 to 10 mm radius (0.159 to 0.212 D) to carry the set screws; that is
within the 0.2–0.33 D hubs carry in practice. The alternative, a local boss leaving the blade
alone, prints with an overhang and has to be indexed against the blades; the joint was the binding
problem, and a slipping impeller costs the whole run.

The row stays registered and `head()` still draws it. A bench measurement, `Po = P/(ρN³D⁵)` from
shaft power at three or four speeds in water, would give it a power number; see `TODO.md`.

### Blade count

4 blades. Measured on otherwise identical folded-blade axial impellers, Po runs 0.79 / 0.99 / 1.34
for 3 / 4 / 6 blades, so going to 6 costs about 35 % more power at the same speed and diameter.

### Spacing

`impeller_spacing_factor = 1.0`, in impeller diameters. This sits at the bottom of the cited 1.0–2.0
band, and below the ~1.55 d at which pitched-blade pairs act independently — so the pair interacts
and power is not simply additive. In terms of tank diameter it is 0.45 T, inside the 0.33–0.5 T that
Nienow specifies for a stacked pair.

The upper impeller is a **mirror** of the lower, not the same part turned over: pumping direction
follows blade handedness and no rotation changes it.

---

## 4. Why large and slow

At **fixed tip speed**, peak dissipation falls as the impeller grows:

```text
ε_max = 1.04 · x · Po^(3/4) · N³ · D²        with v_tip = πND fixed:   ε_max ∝ 1/D
```

Doubling impeller diameter halves the maximum local energy dissipation, because the same power is
spread over a swept volume that grows as D³. At **constant power per volume** in a fixed vessel,
`v_tip` ∝ D^(−2/3) while pumping Q ∝ D^(4/3) — a larger impeller runs slower at the tip _and_ pumps
more. Peak-to-mean dissipation scales as (T/D)³, so moving D/T from 0.33 to 0.50 cuts it by ~3.5×.

This is why shear-sensitive culture wants a large impeller turning slowly, and it runs opposite to
the intuition that gentler means smaller and faster.

**One caution:** "low shear" impellers are not reliably gentle. A low power number can coexist with
a _higher_ peak dissipation than a Rushton turbine. Size the impeller; do not trust the label.

---

## 5. Agitation mode per vessel

Not every registered jar can be agitated the same way, and the reasons are geometric rather than
preferential. Three of the five swept vessels carry no baffles, and **they are unbaffled for two
different reasons** — a distinction `docs/ports-layout.md` did not draw, because it attributes all of
it to the 98 mm mouth floor.

| vessel | mouth | bore  | mouth/T | baffles | why not |
| --- | ----- | ----- | --- | --- | --- |
| `jar_1gal_180x197` | 148 | 170 | 0.871 | 4 | — |
| `jar_10L_220x305` | 142.2 | 210 | 0.677 | 4 | — |
| `jar_6p5gal_305x470` | 137 | 280.8 | **0.488** | 0 | the port circle falls inside the impeller |
| `jar_1gal_155x251` | 95.8  | 149.3 | 0.642 | 0 | mouth below the flange floor |
| `jar_1p5L_112x215` | 88.4  | 103.5 | 0.854 | 0 | mouth below the flange floor |

**The absolute floor**, which the ports document already has: below about 98 mm no baffle fits beside
two Ø16 Atlas probes at any port count. That is `jar_1p5L` and `jar_1gal_155`. Note that `jar_1p5L`
has a _generous_ mouth for its bore — 0.854 — so its problem is absolute size, not proportion.

**The ratio bound**, which it did not: `jar_6p5gal`'s mouth is small relative to its BORE, so the
port circle its lid can offer sits inside the impeller's own sweep. Measured by adding a
three-baffle set and rendering: the flanges fit — 7, 8 and 9-port sets all clear at a 137 mm mouth,
and Oldshue sanctions three baffles at equal projected area — and the vessel then failed on
something else, _"a 126.36 mm impeller leaves no room for a baffle on a 107 mm port circle"_. No port
count reaches it; D/T would have to fall to about 0.20 against a 0.3 floor. **This jar cannot carry a
lid-hung baffle at all**, and the port table is not what stops it.

### The three modes

**Baffled stirred** — `jar_10L`, `jar_1gal_180`. The reference configuration; nothing here changes it.

**Unbaffled eccentric stirred** — `jar_6p5gal`. It is the family's worst case today: the largest
vessel, unbaffled and centred, which Montante measured at flow number **0.25, 65 % below the same
impeller baffled**. It cannot be baffled, but it _builds_, it carries a top-entry drive, and it has
room to offset one. `head()` prices that room: **9.8 mm today, e/T 0.035, worth 15.8 %** of the
centred blend time by Karcz; about **25 mm** with the mount at the Ø36 floor its own gearbox
faceplate allows, e/T 0.090, **worth 31 %**. This is a mount change on a jar that already works, not a new mode of
agitation.

What rides with it, and none of it is small: six of the eight Karcz departures fire here and Reynolds
is one of them; Galletti reports macro-mixing in an eccentric unbaffled vessel is UNSTEADY, the
vortex oscillating slowly rather than sitting; Cabaret reports power RISING with eccentricity; and
Hall's measured `e = 0.2 T` stays out of reach at 0.090.

**Gas-driven** — `jar_1p5L`, `jar_1gal_155`. For these two the eccentric-versus-centred question does
not arise, because neither can carry a shaft to centre or offset. Four things point the same way:

- **Both build failures are assertions about the top-entry drivetrain.** The mount overlaps the port
  flanges by 12.5 mm on `jar_1p5L`; the pH probe runs 6.29 mm through the lower impeller on
  `jar_1gal_155`. Neither assert exists in a configuration without that drivetrain, which the model
  expresses as `drive_name = "none"`; both jars are registered as the airlift built on it.
- **`jar_1p5L`'s impeller is already negated at the design aeration rate.** Oldshue's 8× rule caps
  axial pumping at **0.341 vvm** where the design is 0.5. It is the only vessel in the family that
  floods; the others hold 1.7× to 3.2× headroom. At intended conditions it is a bubble column with a
  spinning obstruction in it.
- **Measured, on this organism, at this scale.** Uyar 2024 ran _C. sorokiniana_ in 2 L
  side-illuminated columns and moved the stirrer from 100 to 200 rpm for **15 %** on kLa and **18 %**
  on mixing time, while the sparger moved kLa **five-fold**. Productivity ranked bubble column 0.097,
  airlift 0.072, stirred tank 0.064 gdw/L·day. The impeller is not what makes a vessel of this size
  work.
- **Swirl is specifically wrong for a side-illuminated column.** Molina Grima: average irradiance
  "considers only the total length of the dark and the light periods, not the frequency of switch".
  Solid-body rotation preserves a cell's radius, so it is close to the worst available flow here —
  the failure is not slow blending, it is that the light/dark cycle never happens.

**An AIRLIFT rather than a plain bubble column**, and the reason is this project's own objection to
leaning on aeration: aeration that mixes as a side effect is an uncontrolled variable. A draft tube
gives a riser/downcomer ratio, a circulation velocity and a circulation time — quantities Uyar
measured at 10.9-12.1 cm/s and 6.1-6.8 s, and which a bubble column does not have at all; that paper
computes circulation time "only for ALR which has a circulation loop, it is not applicable to BCR nor
STR". Uyar's bubble column did out-produce its airlift, but the authors attribute that to the
sparger — microporous against a single 0.8 mm orifice — so it is not evidence that a column beats an
airlift at equal sparging.

**Nor is the airlift expected to out-grow the column.** Sánchez Mirón 2000 ran a bubble column, a
split cylinder and a draft-tube airlift side by side on one alga at one power input and found _"no
significant difference in culture performance"_. What the draft tube buys is the loop — a cell
goes up the core and down the lit annulus — not biomass.

`drive_name = "airlift"` is that mode: the no-drive build plus a draft tube standing on the floor
round everything that hangs from the lid, sparged inside by the ring, which also centres it. On
`jar_1p5L` the tube is 84.7 mm across with A_d/A_r 0.54; on `jar_1gal_155`, 93 mm and 1.72 — the
narrower mouth caps the tube while the bore sets the annulus. The gaps under and over it give the
turn the downcomer's own area, inside Chisti & Moo-Young's 1.65 cap. Chisti's circulation model is
not run: its data start at 1.36 m tall and these loops are under 0.2 m. The DO probe hangs straight
here, because its lean is for the shaft's shadow and inside the riser there is none.

### What outranks all three

**The sparger, and it applies family-wide.** The five-fold kLa spread Uyar measured came entirely
from bubble size: 1.56 mm from a microporous sparger against 4.18-4.25 mm from orifice spargers. This
ring is 8 × 3 mm holes — coarser than the 0.8 mm orifice that gave them 4 mm bubbles. Whatever mode a
jar runs, a finer sparger is worth more than the choice between modes. It is a trade rather than an
oversight: the hole size carries a settled anti-fouling reason, recorded in `TODO.md`. It has not
been priced against the mass transfer it costs, and it should be.

---

## 6. The design basis as it stands

Every figure below is what `head()` reports for `jar_10L_220x305` at the reference fill; the
transcript is `tests/echo/head__jar_10L_220x305.txt`. What was believed before and got wrong is in
`docs/decisions.md`.

### Sparger

Two spargers share the riser from the `air_in` port, and a build names one (`sparger_name`): the
**arm** is the default under the shaft and magnetic drives, and the **ring** under no drive and
the airlift. What `head()` reports for each follows.

#### The arm

- **One straight run under the lower impeller, holes down.** The ring's feed without the ring:
  the same socket and elbow, then a run turned inward from the port circle at r 56.5 to end 5 mm
  short of the shaft at r 9, 66.95 mm off the floor — 10 mm under the lower impeller's blades, so
  the bubbles rise into it. That is where the stirred-tank literature puts a sparger; Birch &
  Ahmed's argument for a ring between the impellers stays with the ring below.
- **Three 3 mm holes, the same size as the ring's for the same anti-fouling reason**, at 3.5 hole
  diameters along the 31.9 mm of bore between the elbow and the end plug, 3.21 m/s each at
  0.5 vvm — inside Barbosa's 0.4–5.4 m/s.
  Bubbles are 5.10 mm at formation, as the ring's; nothing about the arm changes what a 3 mm hole
  makes.
- **The bore is the same departure**: 5.42 m/s in the feed run, open area ratio 1.6875, and
  `head()` names both.
- **The gas supply has to beat 1786 Pa before anything bubbles**: 172.6 mm of culture over the arm
  plus 96 Pa of capillary — 680 Pa more than the ring asked, since the arm sits 69 mm lower.
- **The baffles keep the ring's width, 10.35 mm, under the arm too**, so one set of plates prints
  once. The arm would let them go to 14.5, and at 2 mm nominal to the impeller against 2.28 mm of
  coupling lean that plate can touch the blades; widening them is its own decision.

#### The ring

- **A tube ring at 1.405 D, placed by the mouth.** Birch & Ahmed 1997 tested a ring at 1.4 D — the
  radius at which the annulus outboard of the impeller encloses the volume it sweeps — and found
  better power draw and delayed flooding; Rewatkar & Joshi 1993 recommend a large ring outright.
  So the ring goes as far out as the mouth allows, 132.8 mm on this jar, with 1.25 mm to the
  baffles inboard and 1.25 mm to the mouth on the way in. It is a 6.4 mm octagonal tube on a 4 mm
  bore, split opposite the feed and plugged with two screws so a brush passes through it.
- **It sits between the impellers because the pair converges.** Birch & Ahmed place a ring above an
  up-pumping blade and below a down-pumping one; at `head_shaft_rotation = 1` the lower pumps up
  and the upper down, so one ring at 136.3 mm off the floor — 51.25 mm above the lower impeller and
  43.25 mm below the upper — sits in both discharges. Reverse the rotation and it would need two,
  which `head()` warns on.
- **Eight 3 mm holes, and their geometry is for spacing and against fouling, not for even flow.**
  Rewatkar & Joshi: _"hole size and number of holes have negligible effect when the sparger is
  located near the impeller."_ Even flow is unreachable anyway: 96 Pa of capillary pressure to
  launch a bubble against 2.4 Pa to push gas through a hole, so a fixed tolerance hurts small holes
  most. At 0.5 vvm the holes run 1.21 m/s, inside the 0.4–5.4 m/s Barbosa 2003 actually ran; he
  establishes no critical velocity.
- **What it cannot do is make small bubbles.** Diameter at formation goes as the cube root of hole
  size — 5.10 mm here — so the 1.56 mm of a microporous sparger would want an 86 µm orifice, which
  is why those are sintered. Bubble size is the strongest lever on kLa this design does not have;
  it is the open item.
- **The bore is a departure.** The feed run carries the whole flow at 5.42 m/s with an open area
  ratio of 4.5, and each ring 2.25, so the holes compete with their supply. `head()` names both;
  the fix is a wider riser, which is one designation and a cascade of fits (`TODO.md`).
- **The risers are structure.** Nothing else in the vessel touches the ring, so the five 4 × 0.5 mm
  316 tubes that drop from the tube ports — one feeding, four blind — are what hold it: 1.73 N/mm
  a support, 0.58 mm of sway per newton against 1.25 mm to the baffles. The feed's socket is the
  ring's own tube standing up; the supports' are round, which is the only thing that tells them
  apart at the bottom of a jar.
- **The gas supply has to beat 1104 Pa before anything bubbles**: 103.0 mm of culture over the
  ring plus 96 Pa of capillary. The line's own losses are an order of magnitude more, and the
  sterile filter's slope is extrapolated (`TODO.md`).

### Impeller

- **A 45° four-blade pitched turbine, chosen for what can be said about it.** Medek's correlation
  (Fořt et al. 2002) gives Po 1.492 and a flow number 0.887 from the geometry and names the
  conditions this vessel breaks — T/D and H/T. The hand-drawn helicoid it replaced is
  uncorrelatable (section 3); the switch raised every power, dissipation and torque figure about
  50 %, which is a borrowed number being replaced by a correlated one, not the impeller getting
  worse.
- **Axial over radial, deliberately.** A Rushton disperses gas better — Oldshue's 3× against 8–10×
  of the gas stream's power — but a photobioreactor's criterion is Molina Grima's frequency of
  switch between light and dark, which is pumping. On circulation bought per watt, `N_Q/Po`, the
  axial blade wins by about 4×, and the gas criterion does not bind: at 420 rpm the pair holds its
  flow pattern up to 1.57 vvm against a 0.5 vvm design point.
- **Clearance is 0.9 D, from the source the power number comes from.** Fořt tested pitched blades at
  C/D 0.5 and 1.0 and found hydraulic efficiency higher at 1.0, tying low clearances to solids
  suspension and high ones to blending, which is this reactor's duty. Medek's correlation
  reproduces it, since `Po ∝ (C/D)^−0.165` and `N_Q ∝ (C/D)^0.254`:

  | C/D     | Po        | N_Q       | N_Q/Po    | vs 0.6      |
  | ------- | --------- | --------- | --------- | ----------- |
  | 0.6     | 1.596     | 0.800     | 0.502     | —           |
  | 0.8     | 1.522     | 0.861     | 0.566     | +12.8 %     |
  | **0.9** | **1.492** | **0.887** | **0.594** | **+18.5 %** |
  | 1.0     | 1.467     | 0.911     | 0.621     | +23.9 %     |

  Not 1.0, which is the correlation's own C/D limit and drops coverage over the upper impeller
  below half a diameter. The centreline sits 85.05 mm off the floor (C/T 0.405), leaving 77.0 mm
  under the lower impeller and 51.9 mm — **0.549 D** — of culture over the upper; coverage binds at
  0.949 D. `head()` asserts the shaft still reaches the lower impeller's bore and the upper stays
  submerged, which on this jar spans roughly 0.19 to 1.45 D.

- **Oldshue's 1–2 D does not apply, and that is a class distinction.** His passage is about _"these
  fluidfoil impellers"_, and both halves of it — the allowance and the short-circuiting caveat —
  are fluidfoil statements. On this vessel they could not both be met anyway: the band needs
  C ≥ 94.5 mm and half a diameter of coverage needs C ≤ 89.7 mm, because the column is short for
  two impellers — 2.43 impeller diameters of liquid where the spacing band allows `0.21 < n < 1.43`.
  That band has no primary (Fitschen relays it from Davis, whose sources do not carry it), so
  `head()` reports it and never asserts. The pair stays: the ring sits in its gap and the reference
  build exists (`TODO.md`).
- **The 0.5 D coverage floor is reasoned, not cited.** Oldshue names the concern and gives no
  number; it is where a down-pumping impeller starts drawing its own discharge back off the surface.
  `head()` warns rather than asserts.
- **The uncited C/T convention supported 0.6 D and does not reach 0.9 D.** The quarter-to-third of
  tank diameter usual for an axial impeller maps to C/D 0.556–0.741 in this bore; 0.9 D is above it
  and rests on Fořt alone. No source held here states the convention, so no band function encodes
  it.
- **What the drive does to the culture**, at the rated 320 rpm: Re 47,400, tip 1.58 m/s, 1.70 W
  into 8.17 L = 208 W/m³ mean and 30.4 W/kg peak, the pair under 0.10 N·m of a 0.49 N·m rating;
  blend to 95 % in 4.6 s; kLa 0.0098 s⁻¹ coalescing. Both transfer correlations are extrapolated —
  van't Riet is fitted over 500–10,000 W/m³ and Ruszkowski over 0.01–10 m³ — and `head()` says so.
- **No energy dissipation rate limit exists for any microalga.** The parameter the physics says
  governs has no citable number for these organisms.
- **Speed feedback is specified but not wired.** The drive's encoder resolves 0.89 rpm over 100 ms,
  672 counts per output turn, and nothing reads it yet: tip speed and Re are computed from a
  commanded speed.

### Baffles

- **Three at 120°, one fewer than Oldshue's reference count, and the vessel is under-baffled.** His
  reference is four plates at T/12 running the liquid depth, and he allows three only at the same
  total projected area. These hang from the lid to the floor limit, 10.35 × 274 mm with 224 mm
  submerged, and reach **0.433** of the reference projected area; four reached 0.577. The fourth
  plate's port went to a sampling line (`docs/ports-layout.md`).
  Both levers are spent: depth is at the floor, and the next count that spaces equally on twelve
  ports is four, which would give 0.577 at the cost of that port. Under-baffling lets the vessel swirl rather than mix.
- **The width is capped by the sparge ring, not the bore or the impeller.** The room outside a
  baffle does not grow with the mouth, and a ring wide enough to clear it does not exist, so the
  plate yields: 10.35 mm where the lock bore would pass 17 and the impeller 14.5. Running clearance
  to the impeller is +1.80 mm — 4.08 nominal less 2.28 of lean the coupling's 0.2 mm of play
  allows — and closed.
- **What sized the plate was dynamics, not strength and not collision.** Root stress is about 1 % of
  yield, and the plate bends tangentially while the impeller sweeps a circle, so deflection never
  closes the radial gap. What binds is the first bending mode, which falls as 1/L², and the blade
  passing that sweeps 0–28 Hz on the way to 420 rpm. Stiffness goes as t³ and the mode as t^1.5,
  so thickening raises the crossing toward the 320–420 rpm band the drive runs in: on the 15.3 mm
  plate the crossing sat at 231 / 264 / 297 / 330 rpm for 9 / 10 / 11 / 12 mm, and 12 lands in the
  band. The plate is **10 mm**. On today's narrower plate the mode is 20.0 Hz, crossed by blade
  passing at 299 rpm and by the shaft at 1197, clearing the band by 6 %; the tip deflects
  1.83 mm under 0.77 N, which is over the tenth-of-width limit `head()` warns on. Thicker walks the
  crossing in, so the plate stays at 10 and the warning stands until the area question is settled.
- **The load is reasoned from two directions and neither is cited.** Each plate reacts its share of
  the impeller's torque, `T / (n · r)`; the dynamic pressure of a tangential stream at 0.3 of tip
  speed agrees within 26 %. No source held here loads a baffle. Added mass is not optional in the
  mode: the entrained water is over twice the PETG's own, and leaving it out overstates the
  frequency by about 80 %.
- **Partial and inboard is uncited.** The plates span r 51.3–61.7 mm in a 210 mm bore, so the
  annulus outboard of them is 43 mm wide and unobstructed — a consequence of passing every part
  through a 142.2 mm mouth. Inboard baffles are characterised in the literature, not recommended;
  the relevant papers are paywalled and unread (`docs/references.md`).

- **The plate prints in two dovetailed pieces**, and the joint is in the deflection above: 4.2 mm
  of the plate's 10 crosses the joint plane, 0.074 of its second moment, 0.27 mm of the 1.83 mm at
  the tip. Why it splits where it does, which way the slide runs and what the joint leaves
  unmodelled is in `docs/build.md`.

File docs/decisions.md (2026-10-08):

# Decisions

Two kinds of record, and they answer different questions.

**Settled** is what was decided and why, so it is not quietly redone. Do not re-open an entry
without new evidence — and when you do have it, rewrite the entry rather than leaving it standing
beside the thing that replaced it.

**Corrections** is what this project believed and got wrong. Each entry keeps the old reading in
full, because a figure that survived review is worth more as a warning than as a deletion: most of
them were not typos but readings that were coherent, agreed with the documents around them, and were
measuring the wrong thing. `TODO.md` carries open work only; nothing here is a task.

A corrected figure in a document or in source is replaced where it sits and recorded here; it does
not stay inline.

## Corrections — readings that were wrong

- **The lid seals on a flat land.** It does not. Four of the five registered jars are fire-polished
  and roll over; only `jar_6p5gal_305x470` is ground. The gasket had been sized to a flat that most
  of the family does not have, and the land was doing double duty as the crush stop. Caught by
  measuring jars, not by any check — nothing in the model could have known.
- **`jar_10L`'s baffle can reach the blades, at −0.28 mm running.** It cannot: +2.20 mm. The claim
  was true when written — rendered at `01b9bc2` the model echoes −0.277222 — and went stale when the
  plate narrowed from 15.3 to 10.3454 mm, which opens the gap by half what it takes off the plate.
  **No commit set out to close it.** The cost was baffle area: 0.856 → 0.579 of reference, and six
  plates now reach 0.868 where they used to clear 1.284. A collision was traded for under-baffling.
- **The baffle tilt wants measuring, first.** It does not want measuring at all. The 2.28 mm lean is
  bore play alone with the flange's face contact ignored, so a measurement can only come in at or
  under it — and the clearance already clears there. Every outcome led to the same action, which is
  what makes it not a test.
- **The impeller tip ring earns its place on the strike case.** That case was the −0.28 mm. With
  +2.20 mm the ring has no surviving argument: its steady-load case already put it two orders of
  magnitude past what the fluid asks for.
- **The DO probe collides with the lower impeller on `jar_1gal_155x251`.** It is the pH probe, by
  6.29 mm, and no DO lean reaches it. The old reading came from the only sweep that existed, which
  held both leans flat — the DO probe's worst case and the pH probe's best.
- **A second impeller is added above about H/T 1.2.** The threshold was quoted from this project's
  own document and is on the wrong quantity: the band is written in IMPELLER diameters, and H/T only
  stands in for it at one D/T. Read properly it puts a pair out of reach on four of five jars, not
  three. And it has no primary — Fitschen relays eq. (5) from Davis, whose own two sources do not
  contain it.
- **The working volume is pinned at 8.25 L.** It is 0.865 of what the jar holds. The coverage
  reasoning behind the number still stands — 0.8 of capacity gives 0.374 D against the 0.5 floor —
  but the SCOPE was wrong: a figure chosen for one jar was governing six, and 8.25 L left
  `jar_6p5gal`'s thermocouple in the headspace and stopped that vessel rendering at all.
- **The gasket recess loses its quarter across the 1 mm lands.** There are no lands on four of five
  jars. The excess is an identity — the recess is cut at `t(1−c)`, so `t·c` will not fit whatever
  the gasket — but where it goes splits by lip kind, and on a crown it flows into the 4.762 mm of
  the 8 mm gasket the contact chord never touches. The figures quoted a 3 mm gasket no jar carries.
- **The joint runs at 291.8 N per post and 2.51 MPa.** 352.9 N and 2.78 MPa since the seal moved
  onto the crown, and 351.0 N since the mouth measured 142.2 rather than 143. Worth its own entry because of HOW it survived: the commit that changed the seal
  corrected the echo block `docs/build.md` quotes and left every figure derived from it — the torque
  band, the bolt and rod stretch, a section heading, a ledger entry. Updating a quoted number is not
  the same as updating what was computed from it.
- **The riser's gland must be a counterbore open to the vessel**, because a 4 × 1.5 ring is 7 mm
  across free and cannot be folded through a 4.4 mm bore. Two of the three reasons were wrong. That
  the open face lies on the bed so nothing bridges the bore was **already false** — the shoulder
  above the counterbore is itself a 1.03 mm unsupported ledge. And the ring folds through fine, on a
  printed port. What the counterbore actually did was let the ring fall into the culture. Only the
  third reason survived, and it is why the replacement is a groove rather than a relocation.
- **A magnetic drive is most viable where it is most needed** — thin base, small punt — because the
  gap is base wall plus punt height plus clearance, about 11 mm on `jar_1p5L`. Wrong twice. The
  figures carried two of the three terms the definition names, and a flat driver is not the only
  arrangement: a hub that nests UP INSIDE the punt pays the wall alone, which inverts the ranking,
  because the punt's WIDTH is then both the lever arm and the room for magnets. `jar_1p5L` is the
  worst of the five at 7.5 mm of usable radius; `jar_1gal_155x251` the best at 36.5.
- **The sparge ring is sized at 80 % of the impeller, after Oldshue p. 214.** Two experimental
  studies (Birch & Ahmed 1997, Rewatkar & Joshi 1993) find rings larger than the impeller better;
  the ring is placed by the mouth at 1.44 D. And the flat 4 × 10 section that fit the radial band
  could not be cleaned, so the sparger is a round tube split opposite the feed.
- **The mouth assert charged 8 mm for a tip ring that had been moved inboard of the blades.** The
  D/T caps read 0.4594 and 0.59–0.82 while it did; the ratio was never in danger, only the headroom
  it was chosen on.
- **The clearance was 0.6 D, chosen against Oldshue's 1–2 D as an allowance the vessel could not
  reach.** That allowance is for fluidfoils; Fořt's guidance fits a pitched blade and puts it at
  0.9 D. The uncited C/T quarter-to-third convention supported 0.6 D (C/T 0.27) and does not reach
  0.9 D (C/T 0.405).
- **The eccentricity analysis measured T as the outer diameter.** `docs/references.md`'s e/T
  table read "Hall's e = 0.2 T needs 21.8 mm on `jar_1p5L`", with every ratio 0.2 × or ÷ the glass
  rather than the bore - the impeller-ratio defect, recurring in a document after it was fixed in
  the model. The numerator was lid geometry in mm and never in question; only the denominator
  moved, 4 to 8 % all one way. The e/T columns are echoed by `head()` now, not transcribed.
- **The feed socket is a hexagon.** It takes the tube's own octagonal section now; 0.264 mm of
  corner is what tells it from a round support.
- **Jirout & Rieger's course notes were graded [PR].** Undated teaching material, [TX]; its
  Np = 0.99 ± 0.04 is the borrowed power number the correlated 1.497 replaced.
- **The thermocouple was 3872K117, the same probe at 9 in**, until the model showed it reaching
  through `jar_1gal_180x197`'s floor. `head()` selects the 6 in 1245N31.
- **The metering range was "an 84:1 spread in culture volume".** The ratio was always the flow
  spread; culture volume spans 14.7:1.
- **The baffle plate was 4 mm, then 8, then 9.** Each step was sized on a closed-form deflection
  that was only ever checked at zero freeboard and read 23 % low at the plate's real 49 mm; the
  first mode was the real limit all along, and 10 mm is where the blade-passing crossing clears the
  drive's band. `stirred_tank_baffle_deflection()` integrates the point-load case now.
- **The baffle piece cap was 170 mm, "because 180 mm machines are what a builder owns".** No
  180 mm machine could ever build this reactor: the frame's bases are 257 mm across. The cap is a
  slenderness rule now, and `bioreactor.scad` reports which registered printers take the build.
- **Below D/T 0.4305 the lock bore is what caps the baffle's width.** It was, when the impeller
  and the bore were the only bounds; the sparge ring caps it now on every jar, since the room
  outside a baffle does not grow with the mouth.
- **The full port set's smallest mouth is 130.4 mm and the reduced set's 81.6, and spreading the
  big ports is worth 19.3 mm.** All three assumed the ports could be arranged freely; four baffles
  every third port leave no port that is not beside one, so the worst pair is std against std
  whatever the tubes take. 142.0 and 78.0 mm, which `head()` reports.
- **A DC fan runs 1000–3000 rpm where this design wants 320–420.** The band was the reference
  build's drive on a 94.5 mm impeller, applied to jars whose impellers are half that. The target is
  tip speed, and holding it puts `jar_1p5L` at 528–851 rpm and `jar_1gal_155` at 358–577 — nearer a
  fan's native range than it looked.

## Settled — do not re-open without new evidence

- **The impeller's tip ring is OFF by default, and is a flag rather than geometry.** It is a 4 × 4 mm
  annulus tying the blade tips, and it printed as a floating overhang for most of its circumference —
  86.7 % of it unsupported, longest span 61.6 mm. Nothing structural asked for it: one blade carries
  about 0.62 N at the no-load speed, which is 0.31 MPa at the root and 11 µm of tip deflection, two
  orders of magnitude inside what printed PLA holds, and the blades attach to the hub rather than to
  each other. The strike-against-a-baffle case that kept it went with the +2.20 mm running clearance
  (see the correction above). Measured on the exported part: dropping it removes 4328 mm³, a fifth of
  the impeller, and **does not change the swept diameter** — 94.5001 mm either way, because the blade
  corners define it and the ring sat inboard of them. It is also not part of the shape `pbt_45_4`'s
  power number is defined on, so off is the more faithful geometry as well as the more printable one.
  `impeller_tip_ring = true` restores it if the baffle is ever widened enough to need it.

- **the architecture campaign is done, and these are its refusals.** Eight parts are designated end
  to end - vessel, shaft, plug o-ring, strip light, gasket sheet, motor, DO probe, pH probe -
  reaching the geometry, the readbacks and the exported STL. The rules are in
  `docs/design-conventions.md` ("Three layers, and where a parameter lives", "What the customizer
  can and cannot carry"), `check-designations` guards the surface, and the registries carry names,
  part numbers and provenance
- **REWRAPPING `heat_set_inserts` OR `shaft_couplings` into the `set_screws` shape was refused.**
  That template wraps because the LIBRARY owns the geometry and the row adds purchase identity;
  these are the opposite - the project registers the part in NopSCADlib's own schema - so a wrap
  costs about nine call-site edits in `head.scad` to buy uniformity and nothing else. The insert's
  fields ride the row's tail instead, starting at [11] because the library reads [9] and [10]
- **THREADING THE PORT TABLE through its ~53 call sites was refused**, and a guard against the
  hazard was refused with it. `head_interface_for` gives every probe port `bayonet_std` whatever it
  carries, so no expressible designation can move an interface, and an equality guard would be a
  dead assert by the sweep test. **What reopens it** is a designation that can move a port's
  INTERFACE - a thermocouple thread swap - or one that changes the table's count
- **do not hoist the remaining BUILD rows mechanically.** `0304a3a`'s arithmetic: five moved
  declarations bought one carryable number. Relocation without the name-lookup layer multiplies
  duplicated defaults and carries nothing
- **do not build `motor_for` / `air_pump_for` / `coupler_for` yet.** Those registries hold 4, 1 and
  1 rows; a selection over one candidate is a fit check wearing a selector's clothes. Registering
  rows is the prerequisite, not writing selectors

- **A designation is a STRING, and `"auto"` means derive it.** Not `undef`, which the customizer
  cannot see at all, and not a numeric sentinel: `0` litres or `-1` degrees is exactly the plausible
  number that propagates unnoticed, and on a research instrument a negative lean is a value someone
  could be studying rather than a flag. A string is carried, is visible in the surface, and is
  consumed by a mode branch that never multiplies it by anything. Rejected outright: numeric
  sentinels anywhere
- **Cited bands at the pressure boundary may assert; `reasoned, not cited` limits may not.** The
  three o-ring checks guard the seal between culture and room and come from gland practice rather
  than this project's judgement, so they keep refusal authority. The distinction is the provenance,
  not the severity - which is why the mount slenderness limit loses its
- **No `builds/` escape file yet.** The only thing that genuinely cannot ride a parameter set is a
  nested table, and nobody has needed a custom port table - the two registered sets cover all six
  jars. `-D` is the escape hatch. Revisit only if a custom table becomes recurring; if it is ever
  adopted it must never be rendered with `-p`, which silently un-pins the file's own assignments
- **`peri_pump_frame_mount.scad` is left alone deliberately**, `flange_screw_distance = 48.0` and
  all. It is a stretch goal waiting on a faceplate the bought Kamoer has not got, it blocks nothing,
  and the campaign has enough surface. See the pump item above for what it actually needs

Each of these was asked and answered. The reasoning is in the commit that closed it and, where it
outlives the commit, in `docs/`.

- **the motor mount stays at Ø56.** It can go to 42; below that its base inserts hit the bearing
  pocket. Shrinking buys only eccentricity headroom on a vessel that is baffled anyway, and costs
  stiffness - deflection goes as the cube of height over diameter
- **the lid carries three baffles, not four, for a port.** Four at 90° is Oldshue's reference;
  he allows three at the same total projected area, and these plates cannot widen to give it, so
  three reach 0.433 of his reference on `jar_10L` against four's 0.577. The fourth baffle's port
  went to a sampling line. Going back to four relays the whole lid, since four equally spaced do
  not land on three-at-120°
- **the probes still sit beside baffles at three.** Three baffles leave the middle of each triple
  of ports free of them, but a probe there cannot sit opposite the air inlet, which lands on a
  baffle. DO opposite air in was kept, and the lid is uniform std either way
- **commodity fasteners carry a STANDARD, not a supplier code.** `ISO 4017 M8x30 A2-70` is buyable
  anywhere and does not go stale; nothing in the model reads a property of them beyond nominal size
  and a derived length. The sealing and mount hardware stays pinned by number, because each of those
  carries something a spec does not
- **Cooke's blend-time correlation is deliberately absent.** It could not be made to reproduce the
  figures its own source prints beside it. Ruszkowski's is encoded and was validated first (1.96 s
  against a published 1.9). See `docs/references.md` before trying it again
- **the build runs `impeller_pbt_45_4`, not the twisted paddle.** Po and flow number come from
  Medek's correlation on that geometry; the twisted row stays registered and drawn but has no Po that
  any correlation reaches
- **the shaft is 400 mm and must be a ground rotary shaft.** 300 mm does not exist in the catalogue
  and 200 cannot reach. It runs directly in the 608 bearing's inner race, so plain h9 rod would allow
  0.043 mm and fret the bore
- **the sparge ring sits in the gap between the impellers**, from Birch & Ahmed: above an up-pumping
  impeller, below a down-pumping one. This pair converges, so one ring serves both. Supersedes
  Oldshue p. 214's 80 %-of-impeller ring, which two experimental studies contradict
- **the ring's 8 × 3 mm holes are for spacing and against fouling, not for even flow.** Capillary is
  96 Pa against 2.4 Pa of orifice, so they will not share equally at any count
- **the working volume is DERIVED from a fraction of capacity, not pinned in litres.** 0.865 of what
  the jar holds, which is 8.17035 L on jar_10L and scales to every registered vessel. A litre figure
  is a statement about one jar: 8.25 L left jar_6p5gal_305x470's thermocouple in the headspace and
  stopped that vessel rendering at all
- **the riser is welded hard-temper 316, not seamless soft.** Temper does not move the modulus, but a
  support tube that stays where it is put is the whole point - and it is $22.72/m against $181.42
- **the plug o-ring cord is 3/32 in, not 1/8.** The groove and the port bores are cut into the same
  wall, so a fatter cord fouls the bores on every vessel rather than just a tight one
- **the lid joint is instructed as a TURN, not a torque, and that is not an omission.** 351.0 N per
  post is 0.56 to 0.84 N.m across the 0.20-0.30 nut factor unlubricated 18-8 spans - a 40 % band
  from friction alone, on a fastener that galls, at a setting below most torque wrenches. The turn
  is the gasket's travel over the thread's pitch and has no modulus or friction in it. Both are in
  `docs/build.md`; the torque is there to say why it is not the instruction
- **the lid follows the frame's outer diameter, and trimming it buys nothing.** It was cut to 252
  once - its own floor, being the bolt circle plus a bore plus wall - because 257.40 put it past
  every 256 mm machine by 1.4 mm. Then the FRAME was measured: its base and top base are 257.40 as
  well, and its wall cannot come down because the rod bosses want 36.8 mm of it. So the trim thinned
  the lid's flange and put a 2.7 mm step in the joint to reach a printer the frame ruled out anyway.
  What can print this is REPORTED by bioreactor.scad instead of designed to
- **the baffle cap is a PRINT-QUALITY rule, not a bed one.** It was a literal 170 defended by
  180 mm machines, which could never have built this reactor at all. It is now a piece's height
  against three times its own section - a brim as wide as the part on each side - and the piece that
  binds is the TIP, not the one carrying the port: a flange is a wide foot, so the bare plate is
  half again as slender. Do not re-derive it from a printer; that is the mistake it replaced
- **the riser's gland is an ENCLOSED GROOVE above a 1.2 mm lip.** A counterbore open to the vessel
  has nothing under the cord, so an unseated ring drops into the culture - which is what it did.
  Pressure still seats the cord on the upper shoulder; the lip holds it when there is none. The ring
  is folded and pushed up the bore past the lip, which a printed port proved is reasonable by hand.
  Reversed 2026-09 - see Corrections
- **lights per cord is registered, and it does NOT decide how many lights there are.** These are
  sold as a cord and a controller driving a fixed number of tubes, so a layout that is not a whole
  number of cords buys the next one up. frame() reports the cords a layout needs; the layout stays
  an illumination decision. Deriving the count from the packaging would be letting the shop set the
  design, which is the direction the arrow must not point
- **the baffle's resonance check asks WHERE the mode is crossed, not whether it is near one.** It
  compared the mode against the excitations at the drive's fastest setting and warned within 30 %,
  which is right for load and wrong for resonance: a DC motor sweeps every frequency below its
  maximum, so something is always crossed on the way up. What matters is the SPEED of the crossing
  and whether the drive is asked to hold it - 264 rpm on the 10 mm plate against a 320-420 band, and
  the clearance to that band is reported because that is what separates a 10 mm plate from an 11
- **`check-mesh` is not in `just check`** - it renders solids, which is minutes to tens of minutes.
  The `$fn=0` second pass IS in `check-scad`, because that recipe is the cheap one. Both were proved
  to FIRE on a deliberately broken input before being trusted
- **the two gas-driven jars are registered as airlifts, not bubble columns.** Take the draft tube
  out of the airlift build and what is left is the bubble column: the same lid and parts but for
  the ring, drawn in a few millimetres to fit inside the tube with its supports cut to match, and
  the DO port, which hangs its probe straight. A second registration would export near-duplicate
  parts for a build the airlift's already make.
  `drive_name = "none"` stays a drive the model builds; it is no longer a build the export writes
- **under the airlift the DO probe hangs straight.** Its lean exists to take the tip out of the
  shaft's shadow toward the flow (`docs/ports-layout.md`), and inside the riser there is no shaft and
  the whole core flows. Leaning it only walks it toward a tube that can shift up to 2.5 mm: with
  the tube among its obstacles the lean derived to within 0.08 mm of the wall on `jar_1p5L`, less
  than the tube's own play
- **a magnetic build wanting more floor than the base gives stands on a riser.** The base stays the
  light's floor, so it is one print for every drive on its jar and an airlift build does not grow
  for a drive it lacks. A hollowed deep base was the other way: one print, but under every
  drive, and it moved the jar against the lights. The riser is walls only, so it prints as it
  stands, and it keeps the carrier as it was by carrying the base's slot. `jar_1p5L` keeps its sunk
  floor: its 3.77 mm is far short of the 23.8 mm a riser needs to hold the carrier's ear

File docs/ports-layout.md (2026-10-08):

# Port layout

The lid carries twelve bayonet locks on one circle, 30° apart. They are identical, so what a port
_is_ comes entirely from `head_ports` in `scad/head.scad` — this document is the derivation behind
that table, and the table is the statement of record.

[`ports_layout.drawio`](ports_layout.drawio) is the sketch of the same circle, editable in
draw.io. It was in the repo and referenced by nothing, which is how a diagram goes stale unnoticed.

## Why three baffles, and why they set everything else

An equally spaced count has to divide the port circle. On twelve ports that allows 2, 3, 4, 6 or
12 baffles, and `head()` asserts it rather than trusting the table.

**Three at 120° is a departure, taken for a port.** Four at 90° is Oldshue's reference case (1997
p. 202), and the lid ran four. He allows three, but at _"the same total projected area as exists
with four baffles"_, and this lid cannot widen a plate to make that up: the sparge ring caps the
width and the floor caps the length. So three plates are three quarters of four, **0.433** of his
reference area on `jar_10L` against 0.577. What the fourth plate bought back is a port, and the lid
needs one for a sampling line. `head()` keeps warning that the vessel is under-baffled, and names
four plates as the next count that spaces equally.

Three baffles sit every fourth port, and the remaining nine fall into **three adjacent triples,
one between each pair of baffles**. Going back to four is not a matter of turning one port into a
baffle: four equally spaced do not land on three-at-120°, so it means the whole layout this one
replaced (four baffles every third port, and one tube port fewer).

## The layout

| # | angle | port | function |
| --- | ----- | --- | --- |
| 0 | 0° | tube Ø4.4 | air out |
| 1 | 30° | **baffle** | |
| 2 | 60° | probe | dissolved oxygen |
| 3 | 90° | thermocouple | temperature |
| 4 | 120°  | probe | pH |
| 5 | 150°  | **baffle** | |
| 6 | 180°  | tube Ø4.4 | dose 1 |
| 7 | 210°  | tube Ø4.4 | dose 2 |
| 8 | 240°  | tube Ø4.4 | air in |
| 9 | 270°  | **baffle** | |
| 10  | 300°  | tube Ø4.4 | dose 3 |
| 11  | 330°  | tube Ø4.4 | dose 4 |

Every tube port is bored Ø4.4 for the steel riser it carries; what a port is for is engraved on
its flange. The four dosing ports are numbered, not named: which carries acid, base, media or
anything else is the user's to choose, and any of them can be given to another function.

## The heuristics, and where this layout lands against them

These reduce interference between sensing, aeration, dosing and exhaust while keeping the
arrangement symmetric and manufacturable. Each is checked against the table above.

- **Air in as far as practical from the dissolved-oxygen probe**, so bubbles do not collect on or
  pass over the sensing surface. Air in at 240°, DO at 60° — **180°, the maximum the circle
  allows**. Secondarily from pH, at 120°.
- **Air out separated from air in and the sparger sector**, and away from the expected splash and
  foam region. Air out at 0°, 120° from air in. Impeller circulation direction is a secondary
  preference here, not a prediction.
- **Dosing lines grouped near air in and the mixing sector**, so dosed solution disperses quickly,
  and **away from the pH probe** so a fresh dose does not bias it. Doses 2 and 3, at 210° and 300°,
  sit 30° and 60° from air in and 90° and 180° from pH, so they are the ones for acid and base.
  Dose 1, at 180°, is 60° from pH, and dose 4, at 330°, 150°.
- **Thermocouple adjacent to the DO probe**, so the temperature used for DO compensation comes from
  the same region of liquid. They are at 90° and 60° — **adjacent**. An earlier three-baffle layout
  put the pH probe between them, 60° apart, which did not meet this rule.
- **The other lines distributed through the space** with clearance from baffles, probes, the
  other dosing lines, and the shaft. Dose 1 at 180°, and dose 4 at 330° between two small tube
  ports, which is the port for anything tall that stands on the lid.
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

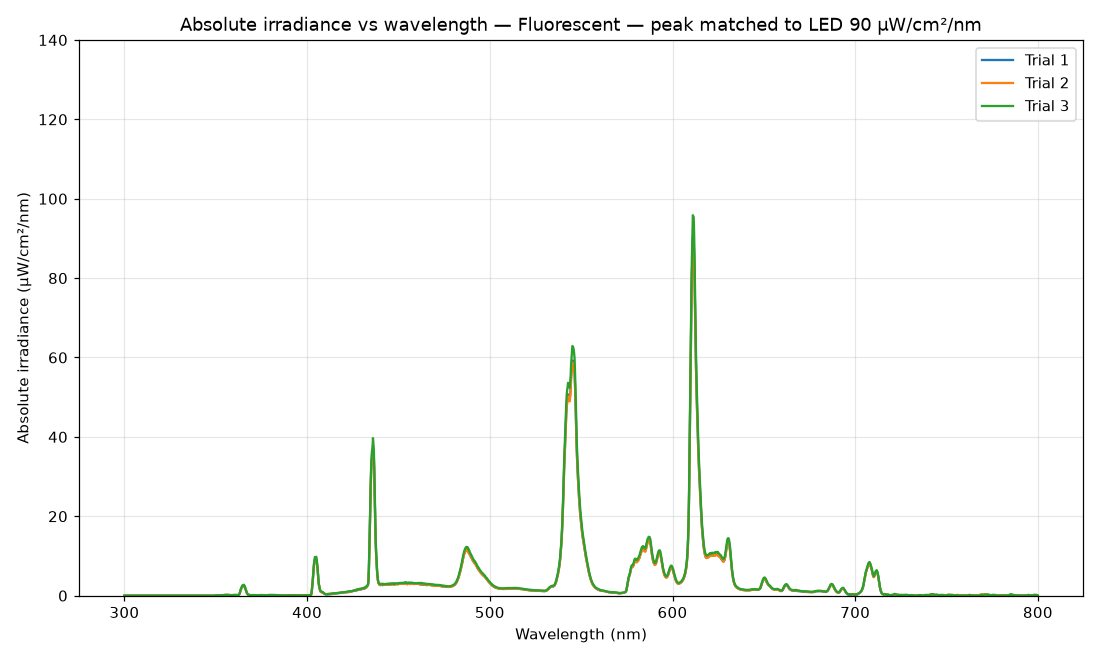
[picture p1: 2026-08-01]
analysis/methods/light-irradiance/figures/flor90uWpeak.png

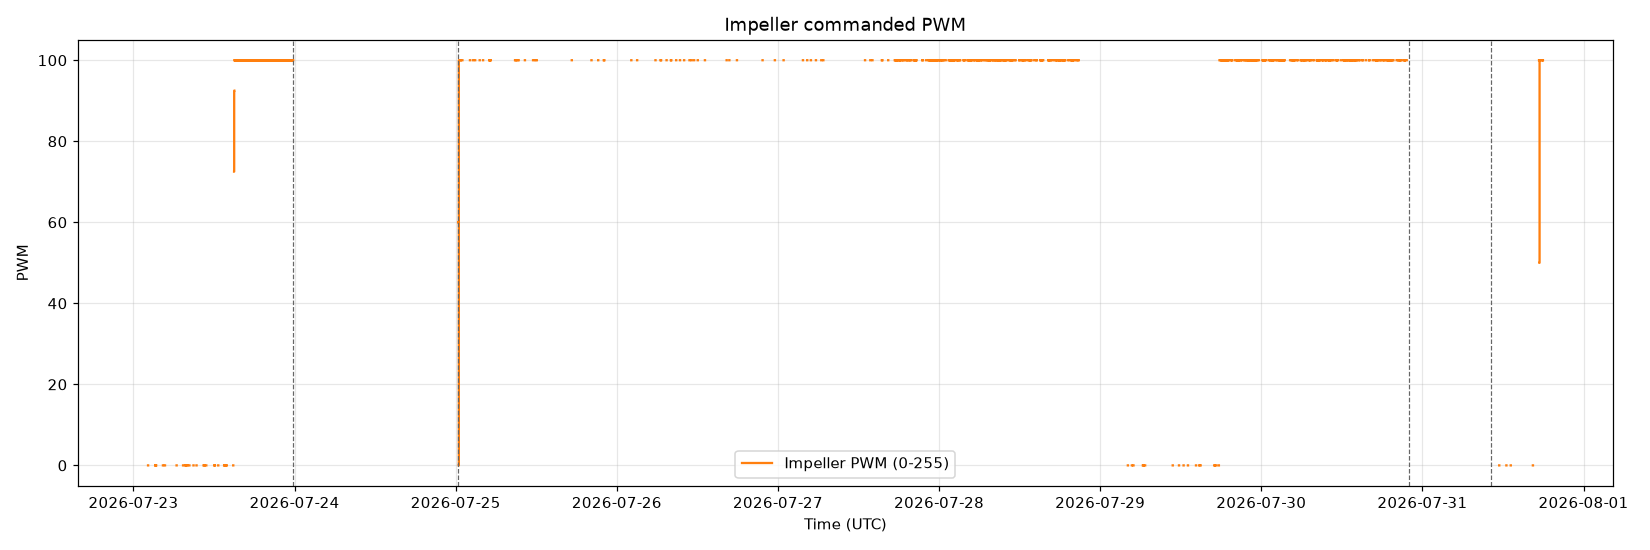
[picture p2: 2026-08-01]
analysis/runs/2026-07-23-chlorella-ccpc90/figures/actuators.png

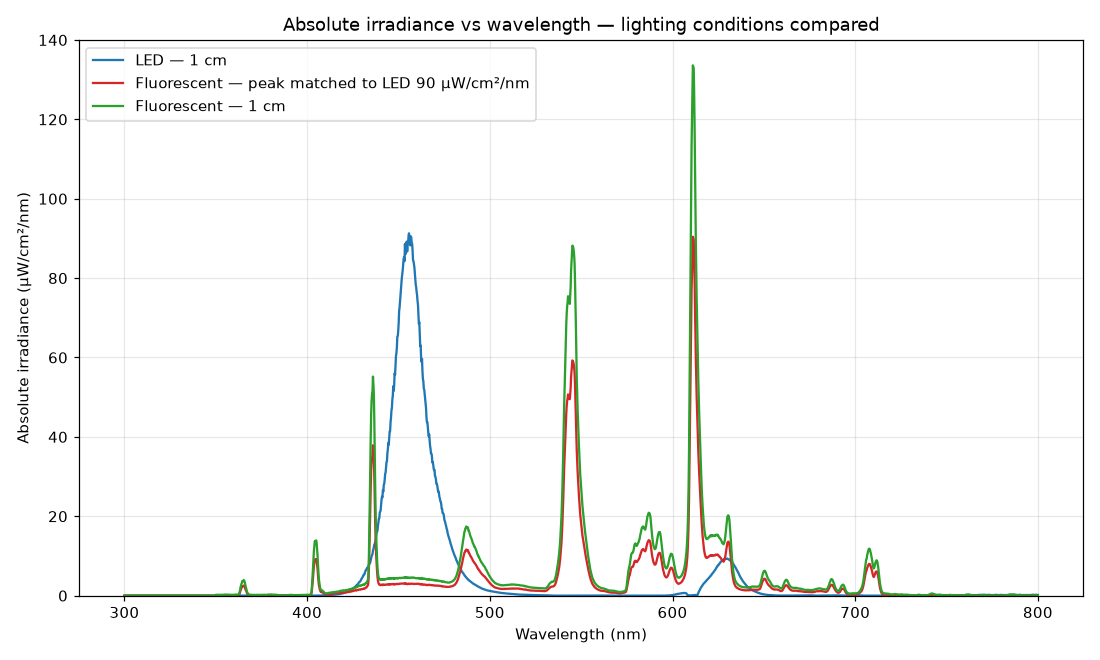
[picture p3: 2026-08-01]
analysis/methods/light-irradiance/figures/combined.png

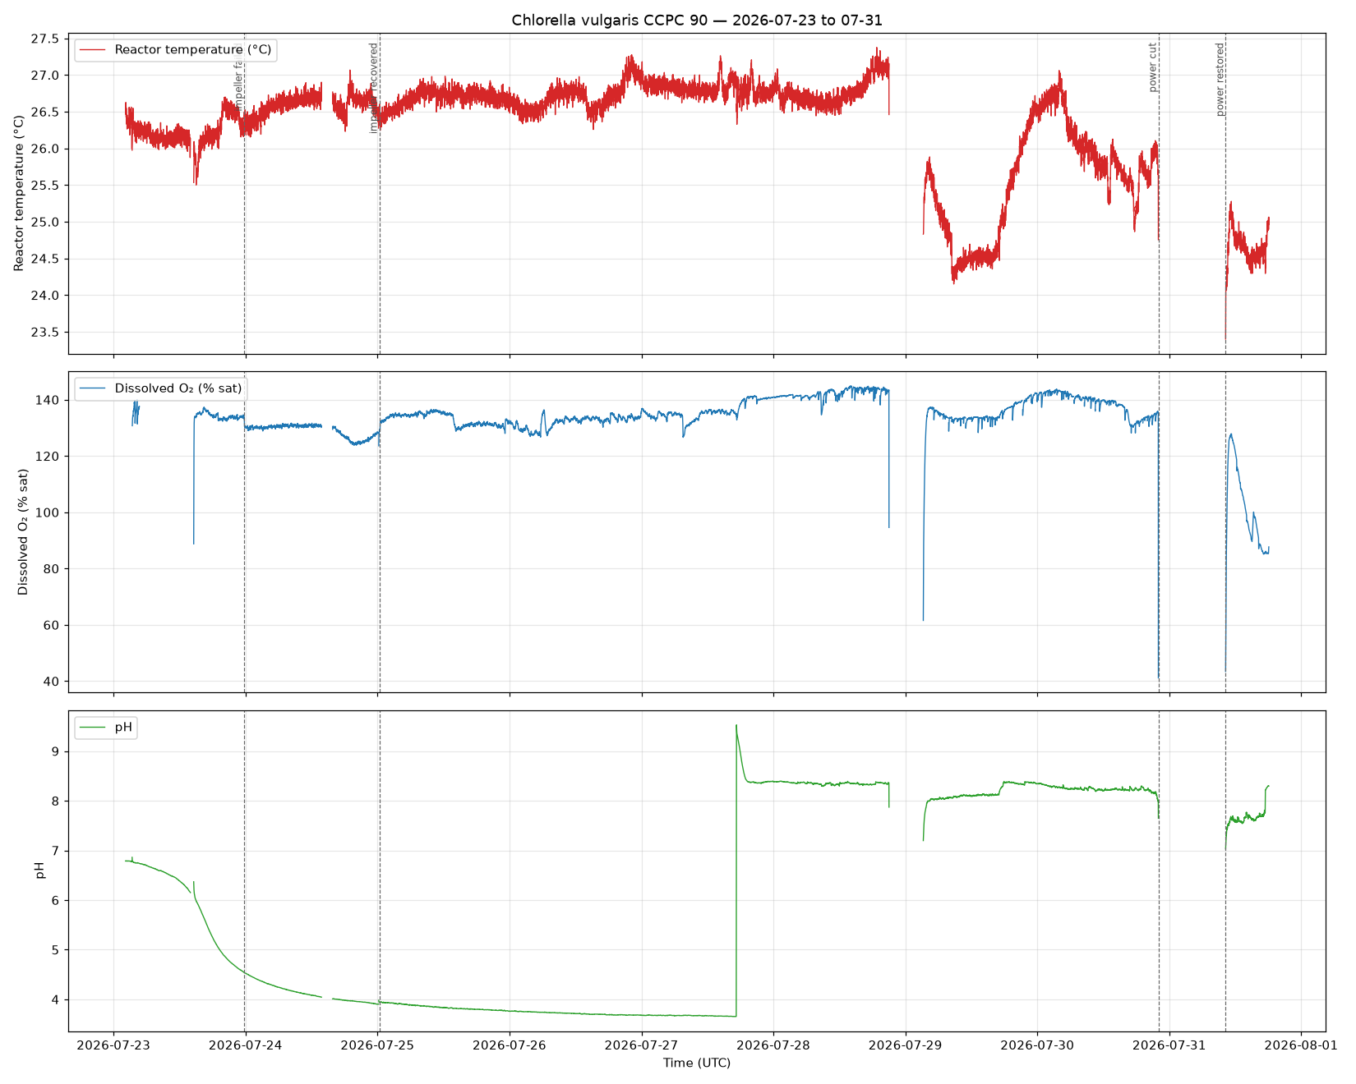
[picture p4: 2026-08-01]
analysis/runs/2026-07-23-chlorella-ccpc90/figures/sensors.png

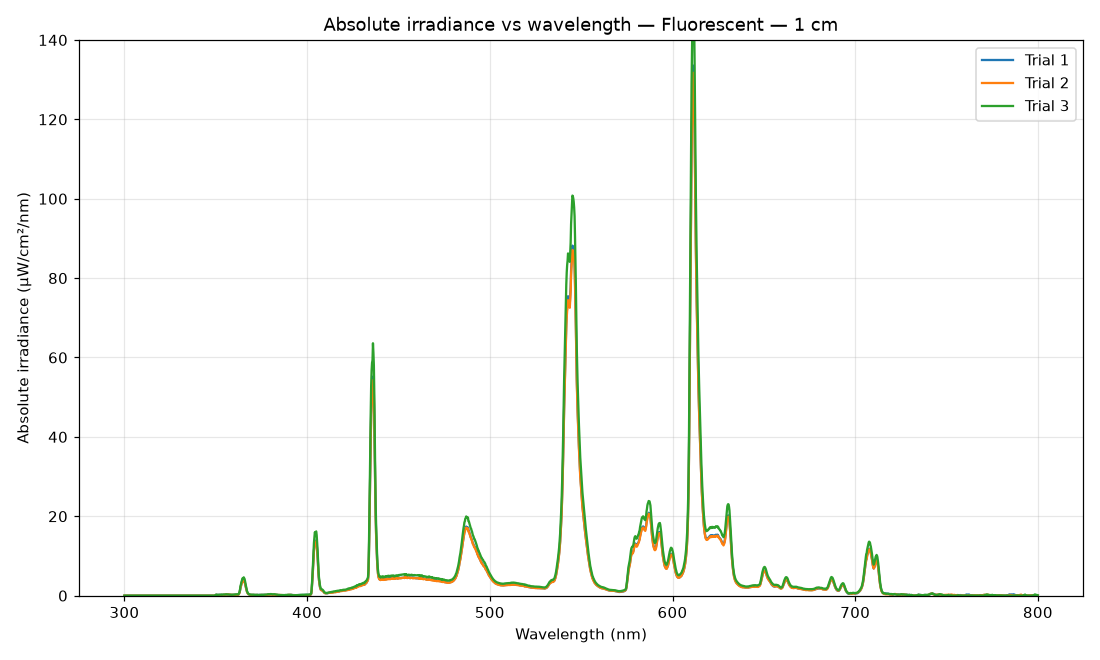
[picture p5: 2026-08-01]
analysis/methods/light-irradiance/figures/flor1cm.png

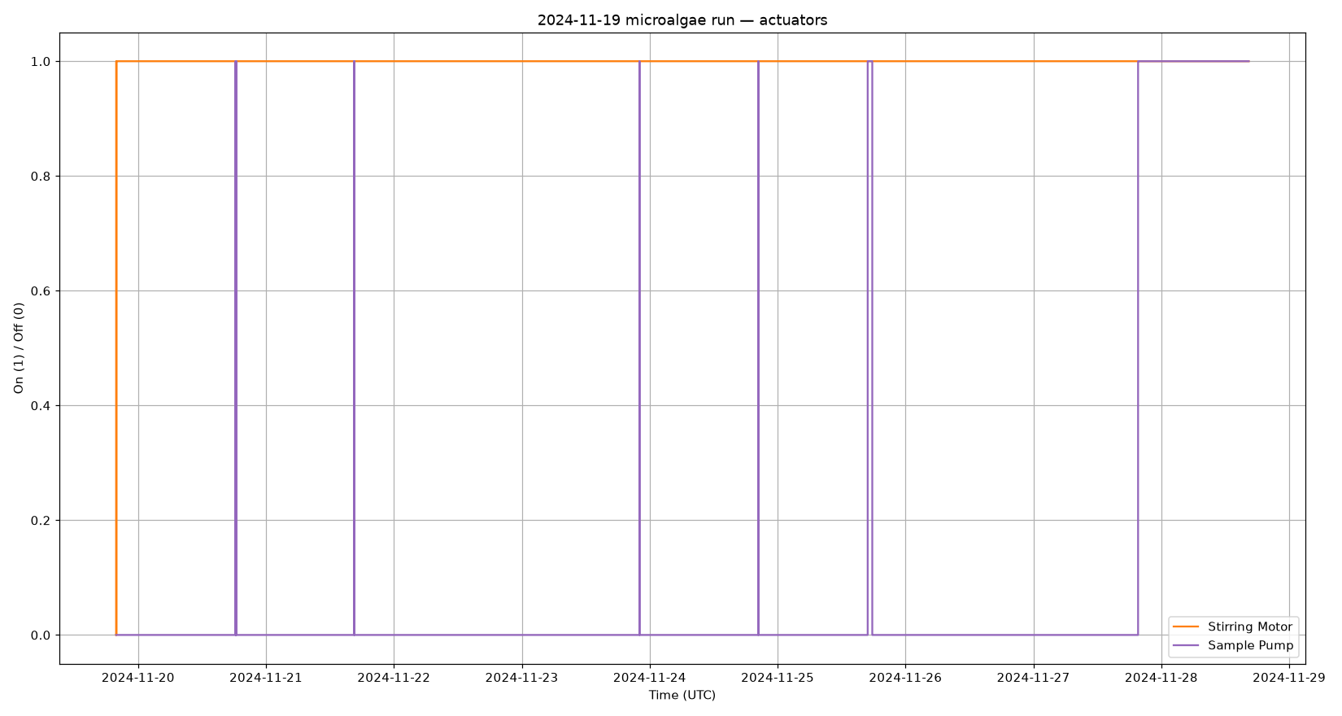
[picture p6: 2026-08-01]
analysis/runs/2024-11-19-microalgae/figures/actuators.png

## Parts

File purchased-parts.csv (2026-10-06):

item | category | brand_model | part_number | qty | source | url | unit_price_usd | price_confidence | key_specs
LED grow light strip (13in, 4 heads) | illumination | 13" LED Grow Light, 3000K Full Spectrum, 4 heads per cord, 192 LEDs, 10 dim levels, 3/9/12 h timer | n/a | 2 packs (=8 strips) | Amazon | https://a.co/d/0gtCMpYn |  | unknown | 3000K full spectrum; 192 LEDs; 10 dim levels; 3/9/12 h timer; 13 in (~330 mm) per head — matches CAD 330 mm pocket. FOUR HEADS PER CORD, which is registered rather than counted by hand: frame() reports what a layout needs, and the 10 L builds' - 4 lights in each of 2 quadrants - is 8 tubes, so 2 cords and nothing spare. Change the layout and that figure moves; these are not sold as tubes, so a layout that is not a whole number of cords buys the next one up and leaves the rest in the box with a controller it does not need
DC planetary gear motor w/ encoder | mixing | E-S Motor 36D DC Planetary Gearmotor with magnetic encoder | RM-ESMO-071 (36PG-555PM-14-EN) | 1 | RobotShop | https://ca.robotshop.com/products/e-s-motor-36d-dc-planetary-gearmotor-w-encoder-12v-420rpm | 36 | approx | listed 49.45 CAD. 12 V DC; 14:1 planetary steel gears; no-load 420 RPM/400 mA; rated 320 RPM, 5 kg-cm (0.490 N-m), <2 A; stall >15 kg-cm, <10 A; motor 36x57 mm, gearbox 36x34.5 mm, shaft 8x20 mm D-shaped; 4-M4 tapped on a 28 mm bolt circle. Encoder is magnetic, 2 channels, 12 PPR at the motor shaft = 672 quadrature counts per output rev; 6 flying leads, no connector. Chosen because 320-420 RPM spans the whole band docs/agitation.md sets, and the encoder retires the no-speed-feedback gap that band was working around. Gearbox length is inferred from the 36PG-3429 sheet at 14:1 - the encoder sheet tabulates none - and the encoder's axial extent is not dimensioned past the can; confirm both before ordering
Air pump / compressor | aeration | ReSun DC 12V Aquarium Air Pump / Compressor Aerator, 35 W | n/a (Amazon/ReSun) | 1 | Amazon | https://a.co/d/05WmQBGO | 45 | approx | 35 W; DC 12 V; rated ~65-70 L/min at ~0.027 MPa. Oversized: the reactor needs 0.817-4.09 L/min for 0.1-0.5 vvm on 8.17 L, and against the whole line this pump settles at 5.80 L/min, so it runs at a fraction of rating. The vessel's own back pressure is 1.79 kPa but the line it actually pushes against is 18.2 kPa, most of it the sterile filter. A flowmeter, a metering valve and a check valve are now all in this BOM - the aeration rate was unmeasurable and unrepeatable while they were not, which made every vvm figure in docs/agitation.md unsettable by a builder. What is left is buying them and taking a reading. Separately, air at 425 ppm supports about 0.09 g/L/day at 0.5 vvm on a 30% utilisation assumption - fine for growing Chlorella, short of 1 g/L/day, which would want ~0.47% CO2. That is an operating choice, not a design one: enrichment happens upstream of the sterile filter and no reactor geometry depends on it. See TODO.md, the measured gas flow item
Dissolved oxygen probe | sensing | Atlas Scientific Lab Grade Dissolved Oxygen Probe | ENV-40-DOX | 1 | Atlas Scientific | https://atlas-scientific.com/probes/dissolved-oxygen-probe/ | 259.99 | firm | 0-100 mg/L; 1-60 C; response ~0.3 mg/L/s; accuracy +/-0.05 mg/L; 1 m cable; SMA/BNC; includes electrolyte
pH probe | sensing | Atlas Scientific Lab Grade pH Probe | ENV-40-PH | 1 | Atlas Scientific | https://atlas-scientific.com/probes/ph-probe/ | 84.99 | firm | pH 0-14; -5 to 99 C; response 95% in 1 s; accuracy +/-0.002; double junction; 1 m cable; SMA/BNC; 100 PSI
Power supply | electronics | Mean Well LRS-150-12 enclosed switching PSU | LRS-150-12 | 1 | Amazon/DigiKey/Mouser | https://a.co/d/0eXy6KHJ | 28 | approx | 150 W; 12 V; 12.5 A; 85-264 VAC in; 88% eff; 159 x 97 x 30 mm; OVP/OCP/OTP
PETG filament | fabrication | Overture PETG 1.75 mm (transparent + grey) | n/a | ~1-2 kg | Amazon/Overture3D | https://a.co/d/0cpq0YfK | 20 | approx | 1.75 mm; 1 kg spool; dim. accuracy +/-0.02 mm; transparent used for culture-contact, grey for structural
Culture vessel | mechanical | Commodity 10 L airtight soda-lime glass jar | n/a | 1 | Alibaba | https://www.alibaba.com/product-detail/10-Liter-Glass-Jar-Airtight-Glass_10000010556695.html | 11.49 | firm | 220 mm OD x 305 mm H; 142.2 mm opening; soda-lime (not autoclave-rated); CAD-confirmed fit
Sealed ball bearing | mixing | McMaster-Carr 440C stainless sealed ball bearing | 6153K71 | 1 | McMaster-Carr | https://www.mcmaster.com/6153K71/ | 15.14 | firm | 22 mm OD x 8 mm ID x 7 mm W; ID tolerance -0.007/0, OD -0.008/0, radial clearance 0.002-0.013 mm (MC3), ABEC 3, Buna-N seals, 304 cage, 34,000 rpm max, -40 to 240 F. Supports the impeller shaft through the head (CAD pocket 22.2, the 0.2 mm allowance over OD). Shaft Mount Type is PRESS FIT: heat the race and chill the shaft. CAUTION - 440C and Buna-N are both poor against bleach, which this chemically-sterilised reactor may use; the shaft is 316 precisely for that reason, so the bearing is the weaker half of the pair. It sits in a blind lid pocket, not submerged. See docs/procurement.md
Rigid shaft coupling | mixing | uxcell 8mm-to-8mm rigid aluminum coupling (L25 x D14, twin set screws) | n/a | 1 | Amazon | https://a.co/d/09Du1zdN | 5.80 | approx | ~25 mm L x 14 mm dia; two set screws per side; sold 2/pack ~11.59 CAD
Impeller shaft | mixing | McMaster-Carr 316 stainless rotary shaft, turned/ground/polished | 1265K66 | 1 | McMaster-Carr | https://www.mcmaster.com/1265K66/ | 37.33 | firm | 8 mm dia x 400 mm. Diameter tolerance -0.005/0 mm, length +/-0.25, straightness 0.18 mm/300, Rockwell B83, chamfered ends. A ROTARY shaft, not plain rod: it runs directly in the 608 bearing inner race, and -0.005/0 against the bearing bore -0.007/0 gives a transition fit of 0.007 mm interference to 0.005 mm clearance, which is what a rotating inner ring wants. Plain rod at h9 would allow 0.043 mm and fret. 316 rather than 303/304 because the reactor is chemically sterilised and never autoclaved, so the shaft meets hypochlorite; McMaster rate 316 for bleach and chlorine. REACH and RoHS 3 compliant. Registered in scad/purchased/shafts.scad alongside 200/600/800 mm cuts of the same part - 1265K64/K67/K68 - for other vessels
M8 threaded rod | mechanical | M8 x 1.25 mm fully threaded rod, A2 stainless | DIN 975 M8 A2 | 1 | McMaster-Carr |  |  | standard | 18-8 (A2) stainless, not plated steel: this is a DRY fastener, and procurement.md sets the rule at wetted->316, dry->18-8. Not 316 either - the chloride resistance that separates them matters for wetted, stagnant exposure, and these meet splash and wipe-down. STRENGTH IS NOT A FACTOR and that is what makes the choice free: head() reports 351.023 N per post against an M8 A2 proof load of about 16.5 kN, so the joint runs at 2.1% of proof. The part_number field carries the STANDARD, not a supplier code - a commodity fastener is fully specified by it and a catalogue number would be region-specific and perishable. Source and url name one place to buy it. STOCK LENGTH, cut to make 4 rods: 4 x 322 mm = 1288 mm for jar_10L, so buy a single length of 1500 mm or more and cut. The 322 is VESSEL-DEPENDENT - 214 mm on jar_1gal_180, 487 on jar_6p5gal - so the cut list follows whichever jar is being built. The row said "steel" while the nuts said "stainless"; they are one material now. structural frame rods; 322 mm cut length, derived in frame.scad as vessel 305 + flange 8 + nut 6.5 + 2.5 mm left proud of the top nut
Rim gasket sheet | sealing | McMaster-Carr water- and steam-resistant EPDM sheet, 1/16 in, 60A | 8525T65 | 1 | McMaster-Carr | https://www.mcmaster.com/8525T65/ | 6.24 | firm | the lid-to-jar pressure boundary, registered as sheet_epdm_1p6_60a. Cut 142.2 x 158.2 mm per lid, echoed at render, so one 12 x 12 in sheet yields ONE - 2 x 158.2 will not fit 304.8. 1/16 in is 1.5875 mm and the lid's recess is cut to 75% of it. The 60A durometer is what sets the ASME VIII-1 gasket factor m = 0.5 and so the 12-post joint; at 75A or harder the same lid wants 16 posts. Replaces an older 142 mm ID silicone gasket row, which named this same seal at a 142 mm ID that falls inside the 142.2 mm mouth, so it would overhang the bore instead of seating on the rim
M8x30 hex head bolt | mechanical | M8 x 1.25 x 30 mm hex head screw, fully threaded, A2-70 stainless | ISO 4017 M8x30 A2-70 | 8 | McMaster-Carr |  |  | standard | 18-8 (A2) stainless, not plated steel: this is a DRY fastener, and procurement.md sets the rule at wetted->316, dry->18-8. Not 316 either - the chloride resistance that separates them matters for wetted, stagnant exposure, and these meet splash and wipe-down. STRENGTH IS NOT A FACTOR and that is what makes the choice free: head() reports 351.023 N per post against an M8 A2-70 proof load of about 16.5 kN, so the joint runs at 2.1% of proof. The part_number field carries the STANDARD, not a supplier code - a commodity fastener is fully specified by it and a catalogue number would be region-specific and perishable. Source and url name one place to buy it. Fully threaded (ISO 4017 / DIN 933) rather than ISO 4014: at M8x30 a part-threaded screw leaves only about 8 mm of plain shank against a 20.4 mm grip, so the thread sits in the joint either way. DO NOT TORQUE TO FASTENER SPEC - see the assembly torque item in TODO.md. clamps the lid flange to the frame's top base. 30 mm is derived: the grip is upper base 10 + lid gap 2.4 + flange 8 = 20.4 mm, and screw_length() rounds up to stock. Buying to the old 18 mm grip would give M8x25, which lands 1.9 mm short of the nut's outer face
M8 hex nut | mechanical | M8 x 1.25 mm hex nut, A2 stainless | ISO 4032 M8 A2 | 20 | McMaster-Carr |  |  | standard | 18-8 (A2) stainless, not plated steel: this is a DRY fastener, and procurement.md sets the rule at wetted->316, dry->18-8. Not 316 either - the chloride resistance that separates them matters for wetted, stagnant exposure, and these meet splash and wipe-down. STRENGTH IS NOT A FACTOR and that is what makes the choice free: head() reports 351.023 N per post against an M8 A2-70 proof load of about 16.5 kN, so the joint runs at 2.1% of proof. The part_number field carries the STANDARD, not a supplier code - a commodity fastener is fully specified by it and a catalogue number would be region-specific and perishable. Source and url name one place to buy it. 18-8 galls: run these on slowly or use anti-seize, especially the 12 that travel the length of a tie rod. 20 = 3 per tie rod x 4 rods, plus 1 per joint bolt x 8. Nut thickness 6.5 mm is read from NopSCADlib's M8_nut and feeds the rod length and the top base's nut pocket, so a thicker nut is not a free substitution
Heat-set insert M4 | mechanical | 18-8 stainless tapered heat-set insert for plastic, M4 x 0.7 | 97163A152 | 1 pack (=10) | McMaster-Carr | https://www.mcmaster.com/97163A152/ | 8.04 | firm | 4 per lid, carrying the motor mount. 4.7 mm installed length into a 5.6 mm hole; the lid keeps 13.25 mm under them. Registered as insert_m4x4p7_ss - the hole is cut from the row, so a substitute changes the print. Brass 94180A351 installs more easily and is the better batch-build choice; see docs/procurement.md for why stainless was taken here
M4x8 socket head screw | mechanical | M4 x 0.7 x 8 mm socket head cap screw, A2-70 stainless | ISO 4762 M4x8 A2-70 | 4 | McMaster-Carr |  |  | standard | 18-8 (A2) stainless, not plated steel: this is a DRY fastener, and procurement.md sets the rule at wetted->316, dry->18-8. Not 316 either - the chloride resistance that separates them matters for wetted, stagnant exposure, and these meet splash and wipe-down. STRENGTH IS NOT A FACTOR and that is what makes the choice free: it only holds the motor mount down. The part_number field carries the STANDARD, not a supplier code - a commodity fastener is fully specified by it and a catalogue number would be region-specific and perishable. Source and url name one place to buy it. McMaster's default socket head cap screw is BLACK-OXIDE ALLOY STEEL, which would rust here - filter to 18-8 explicitly. Threads into an 18-8 heat-set insert, so take care not to round the socket. holds the motor mount to the lid's heat-set inserts. 8 mm is derived from the insert and the mount's 5 mm grip, echoed at render; the inserts only offer 4.7 mm of thread, so a longer screw bottoms out rather than clamping
O-ring AS568-160 EPDM | sealing | EPDM O-ring, AS568-160, 5.237 in ID x 0.103 in CS, 70A | 8785N637 | 1 | McMaster-Carr |  |  | firm | centres the lid plug in the vessel neck; not a second pressure boundary - the sheet gasket is. Stretched onto a groove cut from the jar's bore, so what matters is landing in the window head.scad echoes at render: ID 131.336 to 137.903 mm (0-5% stretch). AS568-160 sits at 3.67% for the registered jar. A 3.53 cord digs too deep for this plug and trips the groove-wall assert
O-ring 23x1.5 EPDM | sealing | EPDM O-ring, 23 mm ID x 1.5 mm CS (26 mm OD), 70A | 8785N383 | 1 pack (=50) | McMaster-Carr | https://www.mcmaster.com/8785N383/ | 7.62 | firm | port face seals, 12 needed - one per port. Every port on this lid takes the std interface: the twelve-port circle puts a probe next to a baffle whatever the tubes do, so a smaller flange on the tubes bought nothing and head_ports_uniform() spends std everywhere it still fits. EPDM, steam and water resistant, -54 to 149 C so autoclavable; ASTM D2000 / SAE J200. Gland is derived from the ID and CS in bayonet_interfaces.scad. Anything under ~21 mm ID cannot seal a port: the coupling's opening is 20.19 mm, so a smaller ring sits over the hole rather than around it
Peristaltic pumps | dosing | Kamoer NKP-DC-S10B peristaltic dosing pump | NKP-DC-S10B | 3 | Amazon/Kamoer | https://a.co/d/0azKoY25 | 10 | approx | 12 V DC, 0.25 A, 5 W; 5.2-90 mL/min; reversible; 3x5 mm silicone tube; snap-in head; 67x55x41 mm ~110 g; ~3.3 direct / ~14 CAD Amazon; driven by Slice_DCMT channels
Sterile inline air filter | aeration | Cole-Parmer sterilizing air filter, 0.2 um hydrophobic PTFE, 50 mm | 1594522 | 1 pack (=10) | Cole-Parmer | https://www.coleparmer.ca/i/cole-parmer-sterilized-air-filter-0-2-m-pore-50mm-dia-10-pk/1594522 | 204.65 | listed (CAD) | ALREADY IN THE LAB - listed so a replicator can buy one. Hydrophobic PTFE membrane in a PP housing, 0.2 um, 50 mm disc, 16.2 cm2 effective area, supplied sterile. Stepped hose barb for 1/4 to 3/8 in (6-9.5 mm) ID tubing, so it needs a step down to the 4 mm line the riser takes. Max 60 psi / 4.1 bar - fifteen times the 3.9 psi the registered pump can dead-head, so pressure rating is not a constraint here. Autoclavable 30 cycles at 121 C / 20 min, or 3 at 134 C / 30 min, which this build does not need since it is chemically sterilised. PRESSURE DROP IS THE SPEC THAT MATTERS AND COLE-PARMER PUBLISH NONE. head() carries 3.45 kPa per L/min as sparge_filter_drop_slope - EXTRAPOLATED from an equivalent 0.2 um PTFE disc of near-identical dimensions, NOT measured. That is 14.09 kPa at the 4.09 L/min design point, twelve times the vessel back-pressure and over half of what the metering valve would otherwise have had to drop. Area-correcting Pall Acro 50 to 16.2 cm2 gives 3.02, so the figure used is 14 % conservative of the best-documented comparable part. Measure it with a water manometer and replace the number - see TODO.md. Price is CAD 204.65 per pack of 10 on the Cole-Parmer Canada listing; the unit_price_usd column carries that CAD figure unconverted.
Raspberry Pi 4B | electronics | Raspberry Pi 4B | n/a | 1 | various |  | 70 | approx | supervisory SBC running Anolis; enclosure is 3D-printed PETG
Slice_DCMT board | electronics | Slice_DCMT dual-channel DC motor controller | n/a | 2 | github.com/feastorg/Slice_DCMT | https://github.com/feastorg/Slice_DCMT |  | TODO | open-source PCB; est. from BOM+assembly. The drive motor ships 6 flying leads and no connector: 2 motor plus 4 encoder (Hall GND/A/B/Vcc). Confirm this board exposes the encoder inputs before relying on closed-loop speed - the model reports what the encoder resolves but nothing reads it yet
Slice_RLHT board | electronics | Slice_RLHT relay + thermocouple interface | n/a | 1 | github.com/feastorg/Slice_RLHT | https://github.com/feastorg/Slice_RLHT |  | TODO | open-source PCB; thermocouple read + 2 relays (relay1 air pump 12V, relay2 LED 5V)
Slice_PHDO board | electronics | Slice_PHDO Atlas EZO-pH + EZO-DO carrier | n/a | 1 | github.com/feastorg/Slice_PHDO | https://github.com/feastorg/Slice_PHDO |  | TODO | open-source PCB; houses EZO-pH + EZO-DO circuits
Type K thermocouple | sensing | McMaster-Carr threaded Type K thermocouple probe for liquids and gases | 1245N31 | 1 | McMaster-Carr | https://www.mcmaster.com/1245N31/ | 96.67 | firm | wire leads; 1/2 NPT male; 6 in L x 1/8 in dia grounded 304 SS probe; 303 SS fitting; 4 ft fiberglass cable; 0.5 s response; max 900 F; ASTM E230 accuracy (+/-4 F from 32-533 F, +/-0.75% above 533 F); not rated below 32 F; for liquids, solids, gas; RoHS/REACH compliant
Set screw M4x6 (impeller hubs) | mixing | 316 stainless cup-tip set screw, M4 x 0.7, hex socket | 92029A142 | 1 pack (=50) | McMaster-Carr | https://www.mcmaster.com/92029A142/ | 12.38 | firm | 4 needed: two per impeller at 120 deg, into the printed PETG hub. Rockwell B80, 2 mm hex. CUP tip, so it bites the Rockwell B83 shaft rather than relying on friction, which is what the existing fit relied on and did not have - the hub bore tapers to exactly the shaft nominal, so grip was zero by design. The hole is printed at the 3.3 mm tap size and the screw cuts its own thread; no thread is modelled. 316 rather than 18-8 because these are wetted and the reactor is chemically sterilised. Registered in scad/purchased/set_screws.scad alongside 92029A144 (M4x8) and 92029A103 (M3x6), which are not bought for this build
O-ring 13x1.5 EPDM | sealing | EPDM O-ring, 13 mm ID x 1.5 mm CS (16 mm OD), 70A | 1289N323 | 1 pack (=50) | McMaster-Carr | https://www.mcmaster.com/1289N323/ | 6.89 | firm | NOT NEEDED FOR THE REFERENCE BUILD - jar_10L_220x305 is uniform std, so nothing on it takes this ring. It is kept because the mini interface is what makes jar_1p5L_112x215 buildable at all: six ports on std wants an 87.6 mm mouth and that jar has 87.5. Buy it only for that vessel. EPDM 70A -65 to 300 F ASTM D2000. The gland has to clear the lock bore it encircles, which is what sets the ID: 2*(lock_bore + land + cs/2). See scad/purchased/orings.scad
O-ring 4x1.5 EPDM | sealing | EPDM O-ring, 4 mm ID x 1.5 mm CS (7 mm OD), 70A | 8785N364 | 1 pack (=50) | McMaster-Carr | https://www.mcmaster.com/8785N364/ | 4.70 | firm | ROD SEAL, and the only one in the build that is: the sparger riser passes up the bore of its port and this closes the annulus around it. FIVE of them on the twelve-port lid, one per tube port - air_in feeds the sparge ring and air_out, media, acid and base drop to it as supports - and three on the six-port jars, which carry no dosing pair. Each sits in an ENCLOSED GROOVE just above the lid's inner face: folded and pushed up the bore past a 1.2 mm lip, and captive after that. It was a counterbore open at that face until 2026-09, which nothing held - the vessel is on that side, so an unseated ring dropped into the culture. Pressure still drives the cord onto the upper shoulder; the lip is what holds it when there is none. ITS ID IS THE TUBE - 4 mm on the 4 mm riser, so it seats at 0% stretch, which head() checks against oring_stretch rather than trusting the pair; the face seals are chosen by the gland they sit in instead, and that is the difference between the two. 18% radial squeeze against the 19-33% a face gland takes - Apple Rubber Table A gives radial glands 14-23%. WHAT IT IS FOR: without it each gas port is a 2.64 mm2 hole into the headspace against a 7.07 mm2 intended vent, so most of the exhaust left by the gap and the inlet sterile filter guarded a vessel that was open to the room. Same EPDM 70A line and the same -65 to 300 F as the port face seals, one size down the same catalogue page, so it is one order. Pack of 50 for two rings. See scad/purchased/orings.scad
O-ring 22x1.5 EPDM | sealing | EPDM O-ring, 22 mm ID x 1.5 mm CS (25 mm OD), 70A | 8785N382 | 1 pack (=50) | McMaster-Carr | https://www.mcmaster.com/8785N382/ | 7.56 | firm | BEARING RIM SEAL, and the last unsealed hole in the lid: the shaft runs through the plug in a bore 0.2 mm over its own and that bore opens into the bearing pocket, so the way out of the vessel was up the shaft, across the bearing face and out around its rim. RADIAL, not a face seal - it sits in a groove cut outward from the pocket wall to 24.46 mm and is squeezed 18% onto the bearing OD. IT SEALS ON THE OUTER RACE, WHICH DOES NOT TURN. A sheet gasket under the bearing face was the alternative and it fails there: the inner and outer race faces are flush on a 608, so anything spanning the face is clamped against steel turning at shaft speed, and clearing the inner race leaves a 1.4 mm band whose width comes from NopSCADlib bb_rim, which its own source calls a guesstimate. ITS ID IS THE BEARING - 22 on 22, so 0% stretch, the same relationship the riser rod seal has with its tube and checked by head() the same way. Same EPDM 70A -65 to 300 F line as every other ring here, so it is one order. Pack of 50 for one ring. See scad/purchased/orings.scad
316 SS tube 4x0.5 mm welded | aeration | 316 stainless welded tube, 4 mm OD x 0.5 mm wall (3 mm ID), hard temper | 50415K21 | 1 | McMaster-Carr | https://www.mcmaster.com/50415K21/ | 22.72 | listed | STOCK LENGTH, cut to make FIVE tubes - the sparger feed riser and four supports, one per remaining tube port - 188.174 mm each as drawn, 14.9375 mm proud of the port for a hose clamp, down to 8 mm inside the socket. 940.869 mm total, so the model asks for the 1 m length at 22.72 and 59.13 mm is left over. The six-port jars take three and would still fit the 0.5 m. Every tube port carries one because the stock says so: a ring held at five bearings instead of two costs nothing that a metre of tube was not already going to supply. WELDED, not seamless: at 4 mm OD the seamless equivalent is 181.42/m against 22.72, is SOFT temper where a support tube wants hard, and comes only in a 1 mm wall so a 2 mm bore. The weld bead costs nothing here - the riser drops a few hundred Pa against the 24 kPa the metering valve burns, and a support tube is a dead leg by design, which is a worse crevice than a bead either way. 4 x 2.5 mm, which this row used to name, is not a size anyone sells. 316 because it is wetted and stays in the culture. The support one is capped at the ring and takes a drilled hole or filed slit at whatever height its own job wants. Deburr the ID after cutting - a wheel cutter rolls a 0.5 mm wall inward.
Rotameter 0-5 L/min | aeration | Dwyer VFA-23 acrylic variable-area flow meter, 0.6-5 L/min air, no valve | VFA-23 | 1 | Dwyer Omega | https://www.dwyeromega.com/en-ca/acrylic-flowmeters-for-gas-liquid-2-4-scales-nist-options/Series-VF/p/VFA-23 | 86.22 | listed (CAD) | Closes the measured-gas-flow gap. 0.1-0.5 vvm on 8.17 L is 0.817-4.09 L/min, so the design point sits at 81.7% of a 5 L/min scale and 0.1 vvm at 16.3% - both on scale, which is what a 0-5 range buys. THE SCALE READS L/MIN, and only one other candidate did: everything McMaster sells in this range reads scfh, where the design point is 8.66 of them and every reading in the paper carries a conversion. CALIBRATION BASIS IS THE SPEC THAT DECIDED IT - Dwyer bulletin F-33 gives 14.7 psia and 70 F, which is this regime, so the correction at the line back-pressure is 0.7%. The medical channel is referenced at 50 psig and the welding channel at 30, which would read 87% wrong here, and that ruled both out entirely rather than on price. Accuracy is 5% of FULL SCALE, so 0.25 L/min, which is 6.1% at the design point; Cole-Parmer have no 5 L/min rung and their nearest tube is 8.5 full scale, costing 10.4% at the same point for 69% more money. THIS IS THE BARE METER. VFA-23-BV carries an integral brass valve whose Cv Dwyer do not publish, so the throttle is a separate characterised part instead - see the metering valve row - and that valve goes UPSTREAM of this meter, which is what the 0.7% correction assumes. Nickel-plated brass body, acrylic block, 1/8 NPT female back or end connection, so it needs NPT-to-barb adapters at both ends. Graduation interval is not published anywhere; over a 70 mm scale it resolves finer than the 0.25 L/min accuracy, so it is worth asking Dwyer but does not blo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
Metering valve | aeration | Clippard MNV-3KP miniature needle valve, 3 degree needle, knurled knob, #10-32 ports | MNV-3KP | 1 | Air Engineering | https://www.airengr.com/store/Clippard/needle-valves.html | 15.11 | approx | The throttle, and it sits UPSTREAM of the rotameter so the meter sees only downstream line loss. Required Cv is 0.0346 at the 4.09 L/min design point: the pump settles at 5.80 L/min against this line, so the valve drops 7.13 kPa on top of the line's own 18.17 - which counts the check valve and the exhaust slot, so this figure moves whenever the line does; head() echoes it. WAS MNV-4K2 AND THE NEEDLE IS WHY IT IS NOT. Both carry the same capacity - Clippard rate each at 5 scfm at 100 psig, which back-solves to Cv 0.094 and confirms the 0.090 in the notes - so both put the design point at about 38% of wide open, 2.6x the required Cv. What differs is the taper: MNV-4 is a 20 degree needle, the COARSEST of the four and coarser than the MNV-1 this project had already rejected as too coarse, while MNV-3 is 3 degrees. Same capacity, same price bracket, roughly seven times the travel for the same flow change. That matters because the pump is seven times oversized, so the whole 0.83-4.13 L/min band is set in the first part of the valve travel. MNV-4K2 was picked on Cv alone without reading the needle diagram. The cost of switching is that MNV-3 has no barbed variant - it is #10-32 both ends and takes two 11792-4-BLK fittings - and adapters were being bought for the rotameter regardless. See docs/procurement.md for how the required Cv moved and what it retired, and the Clippard needle valve catalogue for the taper.
Check valve | aeration | Cole-Parmer miniature check valve, polypropylene body, Viton diaphragm, 3/16 in barb | 5011521 | 1 | Cole-Parmer | https://www.coleparmer.ca/p/cole-parmer-miniature-check-valves-hose-barb-polypropylene-and-viton/88084 | 7.37 | listed (CAD) | Stops culture siphoning back into the pump when it stops. Sits between the metering valve and the sterile filter. 0.18 psi cracking / 0.014 psi closing, published; Cv 0.12. REAL COST TO THE LINE IS 1.85 kPa - 1.24 of cracking plus 0.61 of flowing drop at the 4.087 L/min design point. The flowing half is never on a spec sheet and is what separates otherwise-identical parts: an Air Logic umbrella at the same nominal cracking pressure costs 0.9 kPa more because its flow capacity is a quarter of this one. 3/16 in barb is +19 % stretch on 4 mm ID silicone airline. Barb size barely affects flow here - Cole-Parmer publish Cv per size and it only moves 0.11 to 0.13 across 1/8 to 5/16 - so the barb is chosen to fit the tube, not to chase pressure. CHOSEN ON PROCUREMENT, NOT PHYSICS: US Plastic 22577 is 1.78 kPa, a 4 % difference, which is inside the error on the filter figure that dominates the budget. Same supplier as the sterile filter 1594522 means one shipment, one account, one customs clearance into Canada. Viton rather than the nylon/silicone sibling 5011519: nylon is hygroscopic and swells in continuously humid air. CONFIRM BEFORE ORDERING: the page reads "Working Pressure 3-5 psi" while the pump dead-heads at 3.9 psi and the valve runs at about 2.2 psig in service, so it sits below that band normally and at it on dead-head. The 0.014 psi closing pressure argues it seals fine at low pressure, but the wording is ambiguous. See docs/procurement.md for the other candidates and w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
Tube cutter (316 SS riser) | tooling | McMaster compact metal tube and conduit cutter, 1/8 to 7/8 in OD | 2764A101 | 1 | McMaster-Carr | https://www.mcmaster.com/2764A101/ | 12.30 | listed | Cuts the 316 SS riser stock into 5 x 188 mm. RATED FOR STAINLESS, which is the filter that rules out most cheap tube cutters - many are copper and aluminium only. 1/8 to 7/8 in OD, so the 4 mm (0.157 in) tube sits just above the minimum. Steel cutting wheel, grooved rollers, 1.5 in swing radius, 2 5/8 in long. Replacement wheels sold separately. IT DOES NOT DEBURR. A wheel cutter rolls material inward at the cut and the riser bore is only 3 mm, with that restriction landing exactly where gas enters - so an inside deburring tool is a separate row and a required assembly step, not a nicety. Noga RC1000 (3-5.5 mm) is the only tool found whose range brackets a 3 mm bore. A jeweller''s saw in a mitre jig is the alternative worth considering: a wheel cutter always rolls a thin wall inward, a saw does not, which removes the problem at source rather than fixing it after. Listed REACH and RoHS non-compliant - irrelevant here, it is a bench tool and never enters the reactor, unlike the wetted parts this project does hold to those standards.
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

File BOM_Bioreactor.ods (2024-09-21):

Designator | Component | Number | Cost per unit -currency | Total cost - currency | Source of materials | Material type
N/A | 1.5L Glass Jar | 1 | 3.50 CAD | 3.50CAD | General Store | Glass, Other
N/A | O2 Sensor | 1 | 310.99 USD | 310.99USD | https://atlas-scientific.com/kits/dissolved-oxygen-kit/ | Other
N/A | PH Sensor | 1 | 250 USD | 250USD | https://www.hannainst.com/hi1093b-ph-electrode-with-micro-bulb-and-extended-length.html | Other
N/A | Thermocouple | 1 | 88.71 CAD | 88.71CAD | https://www.mcmaster.com/1245N18/ | Metal, Polymer
N/A | DC Motor | 1 | 60.66 CAD | 60.66 CAD | https://ca.robotshop.com/products/42mm-dc-planetary-gear-motor-12v-1100-rpm | Other
N/A | Aluminum Shaft Coupler | 1 | 1.65CAD | 1.65CAD | https://www.amazon.ca/Fafeicy-Coupling-Flexible-Couplings-Connector/dp/B09CM7KXNJ?s=industrial | Metal
N/A | 8mm Linear Steel Rod | 1 | 12.99CAD | 12.99CAD | https://www.amazon.ca/200mm-Linear-Motion-Shaft-Machine/dp/B08XYQW6DH?s=industrial | Metal
N/A | 8mm ID Shielded Bearing | 1 | 2.57 CAD | 2.57CAD | https://www.digikey.ca/en/products/detail/adafruit-industries-llc/1178/5356858 | Metal
O2Mount | 3D printed PLA O2 Sensor Mount (8.19g) | 1 | 0.25 CAD | 0.25 CAD | N/A | Polymer
PHMount | 3D printed PLA PH Sensor Mount (2.44g) | 1 | 0.07 CAD | 0.07 CAD | N/A | Polymer
ThermocoupleMount | 3D printed PLA Thermocouple Mount (9.88g) | 1 | 0.30 CAD | 0.30 CAD | N/A | Polymer
MotorMount | 3D printed PLA Motor Mount (20.26g) | 1 | 0.61 CAD | 0.61 CAD | N/A | Polymer
Impeller | 3D printed PLA Impeller (11.48g) | 1 | 0.34 CAD | 0.34 CAD | N/A | Polymer
N/A | 3D printed Lid Machining Stencil (9.17g) | 1 | 0.28 CAD | 0.28 CAD | N/A | Polymer
N/A | 3D printed pump stand top (88.36g) | 1 | 2.65 CAD | 2.65 CAD | N/A | Polymer
N/A | 3D printed pump stand side (15.21g) | 2 | 0.46 CAD | 0.91 CAD | N/A | Polymer
N/A | Stone Sparger | 1 | 0.83 CAD | 0.83 CAD | https://www.amazon.ca/dp/B075QCWGZQ?s=pet-supplies&sp_csd=d2lkZ2V0TmFtZT1zcF9kZXRhaWw | Other
N/A | Peristaltic Pump | 3 | 12.00 CAD | 36.00 CAD | https://www.amazon.ca/Kamoer-Peristaltic-Hydroponics-Nutrient-Analytical/dp/B07GWJ78FN | Other
N/A | Air Pump Kit | 1 | 43.08 CAD | 43.08 CAD | https://www.amazon.ca/Uniclife-Aquarium-Adjustable-Single-Accessories/dp/B06XS1DCG6 | Other
N/A | 2 meter, 2mm ID Silicone Tubing | 2 | 9.99CAD | 19.98CAD | https://www.amazon.ca/Uxcell-a15121600ux1002-Translucent-Tube-Water/dp/B01AUQ3JBK | Polymer
N/A | 1 meter, 6mm ID Silicone Tubing | 1 | 10.99CAD | 10.99CAD | https://www.amazon.ca/Silicone-Flexible-Rubber-Tubing-Transparent/dp/B08GPD22ZC | Polymer
N/A | 8-Feet, 4mm ID Silicone Tubing | 1 | 2.97 CAD | 2.97 CAD | https://www.amazon.ca/Penn-Plax-Standard-Airline-Tubing-Accessories/dp/B0002563MM | Polymer
N/A | PTFE Air Filter | 1 | 15.32 CAD | 15.32CAD | https://www.coleparmer.ca/i/cole-parmer-essentials-sterilized-air-filter-0-2-m-pore-50mm-dia-10-pk/1594522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 | Polymer
N/A | Straight Tube Reducers | 2 | 1.08CAD | 2.16CAD | https://www.mcmaster.com/5372K841/ | Polymer
N/A | 250ml Glass Bottles | 3 | 3.50 CAD | 10.50CAD | https://www.amazon.ca/HINGWAH-Bottles-Beverages-Kombucha-Included/dp/B091BTHKKN | Glass
N/A | M3x15 Screws | 20 | N/A | 10.98 CAD | https://www.amazon.ca/XunLiu-Grade-Button-Socket-Screws/dp/B0756VBG6B | Metal
N/A | M3 Nuts | 20 | N/A | 9.28 CAD | https://www.amazon.ca/uxcell%C2%AE-0-5mm-Insert-Stainless-Finish/dp/B07LF11D7V (https://www.amazon.ca/uxcell®-0-5mm-Insert-Stainless-Finish/dp/B07LF11D7V) | Metal
N/A | Ni-Chrome Wire | 2.5m | 11.22CAD | 28.05CAD | https://www.omega.ca/en/accessories/electrical-components/heating-wire-and-cables/ncrr-series/p/NCRR-28-100 | Metal
 |  |  | Total | 1120.58 CAD

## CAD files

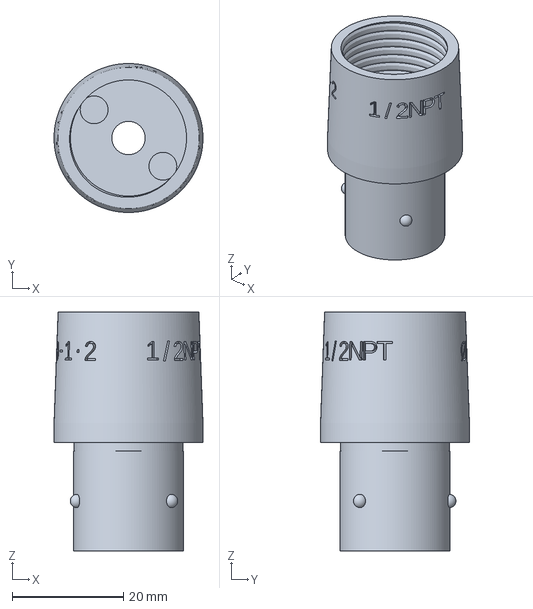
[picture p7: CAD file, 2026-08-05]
printing/thermocouple_mount_pins.3mf
26.8 x 26.8 x 43.0 mm

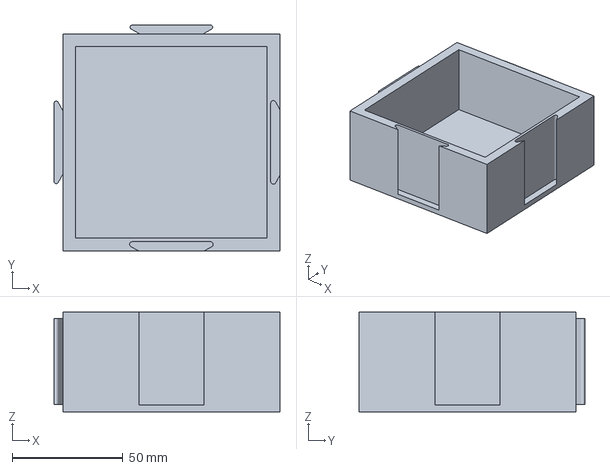
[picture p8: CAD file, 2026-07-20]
printing/bottle_holder_duran.3mf
102.1 x 102.1 x 45.0 mm

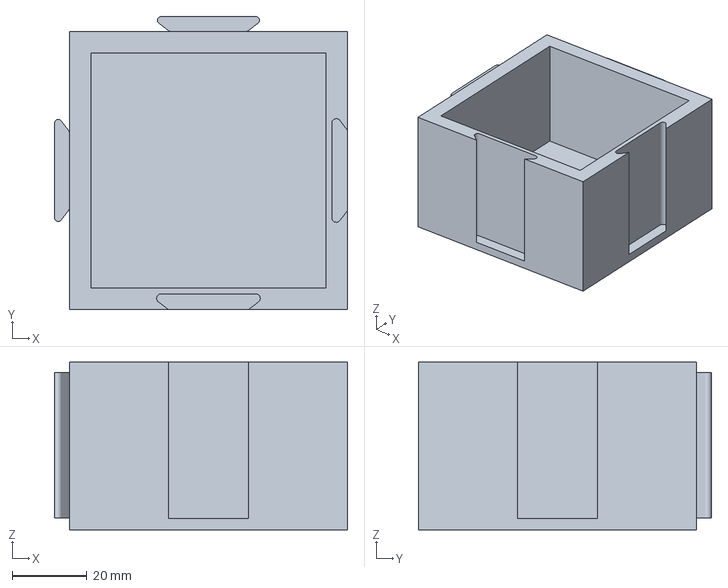
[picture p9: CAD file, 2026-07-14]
printing/bottle_holder.3mf
78.6 x 78.6 x 45.0 mm

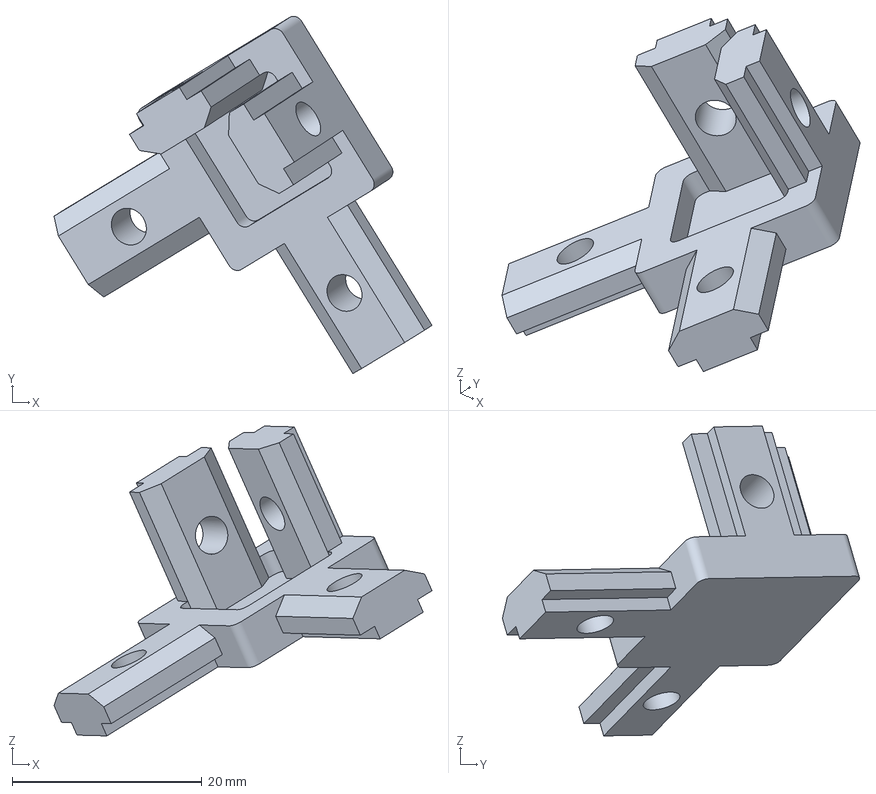
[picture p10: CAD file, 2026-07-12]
printing/electronics_stand_corner_bracket_v1.3mf
39.8 x 37.6 x 32.6 mm

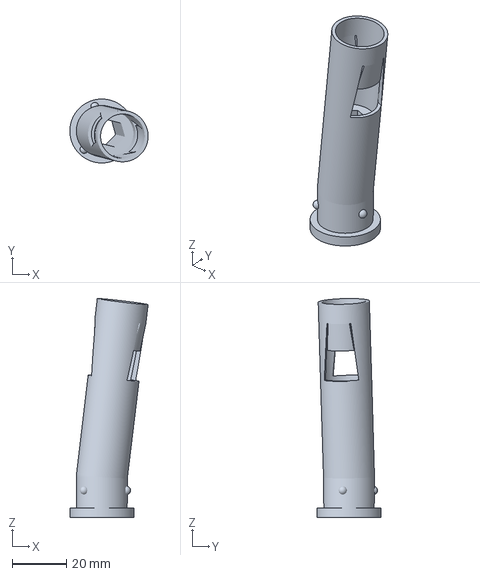
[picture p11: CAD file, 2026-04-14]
printing/bayonette_probe_port_PC.3mf
28.9 x 23.6 x 80.8 mm

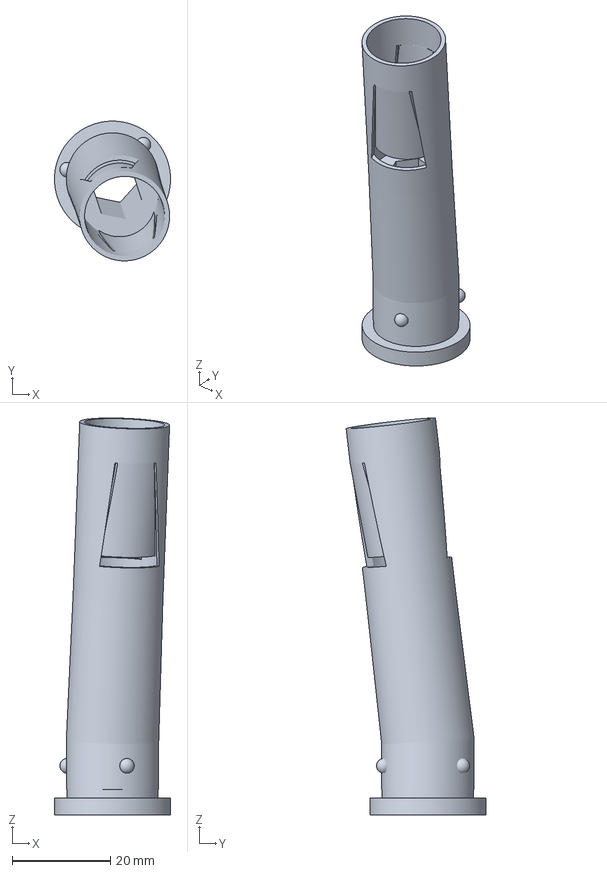
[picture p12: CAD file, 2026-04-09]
printing/bayonette_probe_port_PP.3mf
23.6 x 28.4 x 80.7 mm

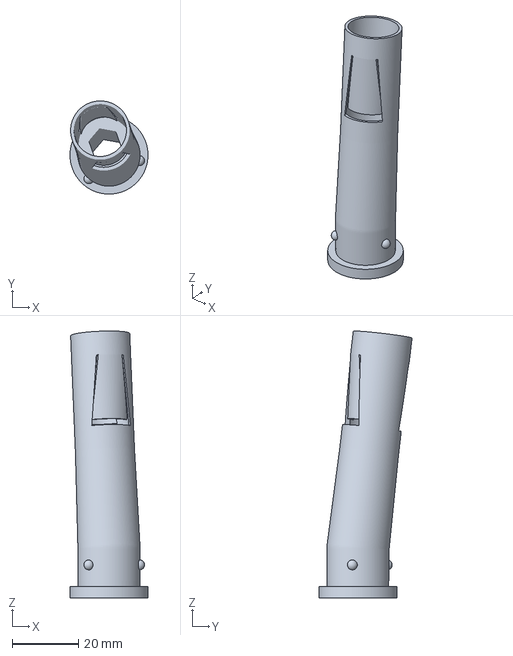
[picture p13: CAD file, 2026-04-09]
printing/bayonette_probe_port.3mf
23.6 x 28.2 x 80.7 mm

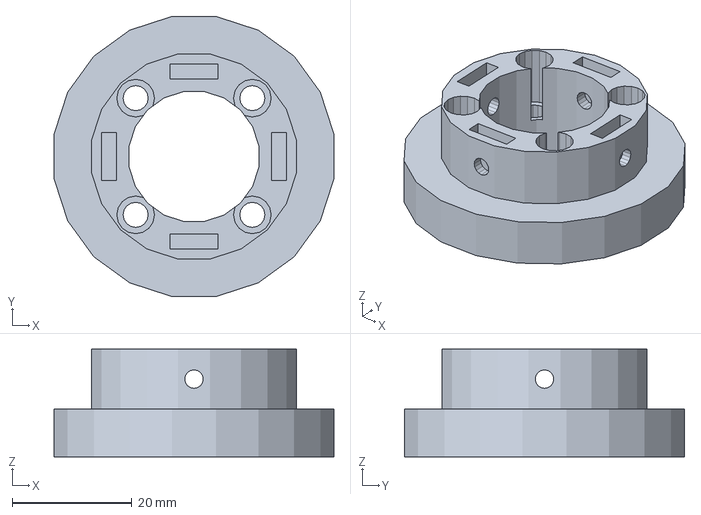
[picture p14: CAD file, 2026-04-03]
printing/motor_mount_new_top.3mf
46.8 x 46.8 x 18.0 mm

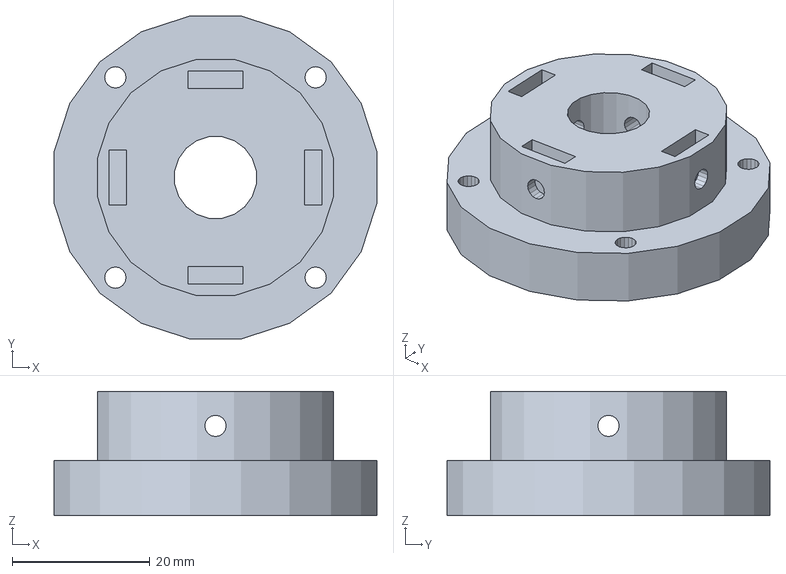
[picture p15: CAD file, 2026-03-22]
printing/motor_mount_new_base.3mf
46.8 x 46.8 x 18.0 mm

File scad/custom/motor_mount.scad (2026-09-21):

/**
 * @file motor_mount.scad
 * @brief Three-part telescoping motor mount
 * @author Cameron K. Brooks
 * @copyright 2026
 *
 * For standard cylindrical electrical motors which have a circular faceplate with 4 screws
 * in a square pattern, and a central shaft. Built as two identical male end caps joined by a
 * female middle tube, so the standoff height is set by one parameter; part_to_render selects
 * one part for printing or "all" for the assembled view.
 */

z_fight = $preview ? 0.05 : 0; // z-fighting avoidance for preview
$fn = $preview ? 64 : 128;

// Function to get the (centered) distance between the base holes. Leaves 1.5 hole diameters from
// centre to the body's edge, so the counterbore over it - one hole diameter in radius - always
// keeps half a hole diameter of wall, whatever the body is scaled to.
function get_base_screw_separation_radius(body_diameter, screws_diameter) = (body_diameter - screws_diameter * 3) / 2;

// The flange left under a base screw's head: the counterbore floor is halfway down it, so this
// is what the screw grips before it reaches whatever the mount is bolted to.
function motor_mount_base_screw_grip(wall_thickness) = wall_thickness / 2;

module motor_mount(
  height,
  body_diameter,
  wall_thickness,
  screws_diameter,
  base_screw_hole_diameter,
  shaft_diameter,
  motor_faceplate_bolt_circle_dia,
  motor_boss_diameter,
  coupling_allowance,
  vertical_hole_allowance = 1.1,
  horizontal_hole_allowance = 0.1,
  boss_allowance = 0.4,
  facets = 20,
  part_render = "all"
) {

  // ----- derived params -----

  coupling_screw_diameter = screws_diameter + horizontal_hole_allowance;

  motor_screw_diameter = screws_diameter + vertical_hole_allowance;

  // The hole is a facets-sided polygon, so the boss has to pass its inscribed circle.
  motor_boss_hole_diameter = (motor_boss_diameter + boss_allowance) / cos(180 / facets);

  raised_face_height = wall_thickness;

  flange_height = wall_thickness;

  // The base screws fasten the mount to whatever carries it, so they are sized and placed by
  // that joint, not by the gearbox. Driven off the hole rather than a nominal size because the
  // caller owns the screw and so knows its real clearance.
  base_screw_separation_radius = get_base_screw_separation_radius(body_diameter, base_screw_hole_diameter);

  middle_height = height - flange_height * 2;

  middle_inner_diameter = body_diameter - wall_thickness + coupling_allowance;

  // ----- assertions -----

  // facets must be divisible by 4 (screws are placed every 90°) while providing rough
  // poly such that the parts cannot concentrically rotate relatively to each other
  assert(facets % 4 == 0, "facets must be divisible by 4 for screw holes to be properly placed");

  // The mount telescopes to reach the shaft, so its height is derived from the vessel it stands
  // over and can come out negative on a tall one. Nothing downstream notices, so it is caught here.
  assert(
    middle_height > 0,
    str("Motor mount is ", height, " mm tall, which leaves ", middle_height, " mm of middle stand between two ", flange_height, " mm flanges.")
  );

  // The body is a free choice and the bolt circle comes with the gearbox, so nothing but this
  // makes the mount wide enough for the motor it was picked to carry.
  assert(
    motor_faceplate_bolt_circle_dia / 2 + motor_screw_diameter <= body_diameter / 2,
    str(
      "The gearbox's screws counterbore out to r ", motor_faceplate_bolt_circle_dia / 2 + motor_screw_diameter,
      " on a ", body_diameter, " mm body."
    )
  );

  // ----- build -----

  // The base plate side
  if (part_render == "all" || part_render == "base_plate") {
    male_end(
      center_hole_diameter=shaft_diameter * 1.5,
      vertical_hole_separation_radius=base_screw_separation_radius,
      vertical_hole_diameter=base_screw_hole_diameter,
      flange_height=flange_height,
      raised_face_height=raised_face_height,
      body_diameter=body_diameter,
      wall_thickness=wall_thickness,
      coupling_screw_diameter=coupling_screw_diameter,
      facets=facets
    );
  }

  // Motor interface side
  if (part_render == "all" || part_render == "face_plate") {
    translate([0, 0, middle_height + flange_height * 2 + z_fight / 2])
      rotate([0, 180, 0])
        male_end(
          center_hole_diameter=motor_boss_hole_diameter,
          vertical_hole_separation_radius=motor_faceplate_bolt_circle_dia / 2,
          vertical_hole_diameter=motor_screw_diameter,
          flange_height=flange_height,
          raised_face_height=raised_face_height,
          body_diameter=body_diameter,
          wall_thickness=wall_thickness,
          coupling_screw_diameter=coupling_screw_diameter,
          facets=facets
        );
  }

  if (part_render == "all" || part_render == "middle_stand") {
    translate([0, 0, flange_height + z_fight])
      middle_pipe(
        pipe_height=middle_height,
        inner_diameter=middle_inner_diameter,
        raised_face_height=raised_face_height,
        body_diameter=body_diameter,
        coupling_screw_diameter=coupling_screw_diameter,
        facets=facets
      );
  }
}

module male_end(
  center_hole_diameter,
  vertical_hole_separation_radius,
  vertical_hole_diameter,
  flange_height,
  raised_face_height,
  body_diameter,
  wall_thickness,
  coupling_screw_diameter,
  facets
) {
  // the head's pocket follows the hole it sinks into, so each end plate counterbores its own
  // screw rather than both ends following the motor's
  counterbore_diameter = vertical_hole_diameter * 2;

  difference() {
    union() {
      cylinder(h=flange_height, d=body_diameter, $fn=facets);
      translate([0, 0, flange_height]) cylinder(h=raised_face_height, d=body_diameter - wall_thickness, $fn=facets);
    }

    // Center hole for the motor shaft / boss
    translate([0, 0, -z_fight / 2])
      cylinder(h=raised_face_height + flange_height + z_fight, d=center_hole_diameter, $fn=facets);

    // Vertical holes
    for (i = [0:3])
      rotate([0, 0, i * 90])
        translate([vertical_hole_separation_radius, 0, -z_fight / 2])
          cylinder(h=flange_height + raised_face_height + z_fight, d=vertical_hole_diameter, $fn=16);

    // Vertical counterbores
    for (i = [0:3])
      rotate([0, 0, i * 90])
        translate([vertical_hole_separation_radius, 0, flange_height / 2])
          cylinder(h=raised_face_height + flange_height, d=counterbore_diameter, $fn=16);

    // Horizontal holes for screws to fix the female middle tube to each male end
    for (i = [0:3])
      rotate([0, 0, i * 90 + 45])
        translate([0, 0, flange_height + raised_face_height / 2])
          rotate([0, 90, 0])
            cylinder(h=body_diameter, d=coupling_screw_diameter, $fn=16);
  }
}

module middle_pipe(
  pipe_height,
  inner_diameter,
  body_diameter,
  raised_face_height,
  coupling_screw_diameter,
  facets
) {

  difference() {
    cylinder(h=pipe_height, d=body_diameter, $fn=facets);
    translate([0, 0, -z_fight / 2])
      cylinder(h=pipe_height + z_fight, d=inner_diameter, $fn=facets);

    // Horizontal holes for screws to fix the female middle tube to the lower base
    for (i = [0:3])
      rotate([0, 0, i * 90 + 45])
        translate([0, 0, raised_face_height / 2])
          rotate([0, 90, 0])
            cylinder(h=body_diameter, d=coupling_screw_diameter, $fn=16);

    // Horizontal holes for screws to fix the female middle tube to the upper top
    for (i = [0:3])
      rotate([0, 0, i * 90 + 45])
        translate([0, 0, pipe_height - raised_face_height / 2])
          rotate([0, 90, 0])
            cylinder(h=body_diameter, d=coupling_screw_diameter, $fn=16);

    // Cut out 4 windows for access to the screws that fix the top to the motor faceplate
    for (i = [0:3])
      rotate([0, 0, i * 90])
        translate([0, 0, pipe_height / 2])
          rotate([-90, 0, 0])
            linear_extrude(height=body_diameter)
              resize([body_diameter * 0.40, pipe_height * 0.80])
                circle(d=1, $fn=100);
  }
}

// ----- example values -----
//
// A worked example on M3 screws; this file's render is a preview.

_mm_screws_diameter = 3;

// clearance hole for the screws holding the mount down; an M3's, to match the example above
_mm_base_screw_hole_diameter = 3.4;

_mm_shaft_diameter = 8.0;

_mm_motor_faceplate_bolt_circle_dia = 27.6;

_mm_motor_boss_diameter = 22.0;

// ----- design selections -----

_mm_body_diameter = 56.0;

_mm_wall_thickness = 10.0;

_mm_height = 141;

_mm_allowance_fit = 0.2; // clearance for printed parts

_mm_part_to_render = "all"; // ["all", "base_plate", "face_plate", "middle_stand"]
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

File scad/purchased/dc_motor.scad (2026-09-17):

/**
 * @file dc_motor.scad
 * @brief DC motor model, optionally fitted with a gearbox
 * @author Cameron K. Brooks
 * @copyright 2026
 *
 */

use <gearbox.scad>

light_grey = [0.6, 0.6, 0.6];
medium_grey = [0.5, 0.5, 0.5];

function dc_motor_name(type) = type[0];
function dc_motor_part_number(type) = type[9]; // undef where nothing is sold
function dc_motor_diameter(type) = type[1][0]; // diameter of the motor
function dc_motor_length(type) = type[1][1]; // length of the motor
function dc_motor_shaft(type) = type[2]; // [shaft_d, shaft_l] of the bare shaft, optional
function dc_motor_gearbox(type) = type[3]; // gearbox type mounted to the face, optional
function dc_motor_boss(type) = type[4]; // [boss_d, boss_l] raised boss around the shaft exit, optional
function dc_motor_face_screws(type) = type[5]; // [cdist, screw_d] of the motor's own face screws, optional
function dc_motor_output_speeds(type) = type[6]; // [no_load_rpm, rated_rpm] at the output, optional

// Either half can be undef on its own; callers check the half they use.
function dc_motor_no_load_output_rpm(type) = is_undef(type[6]) ? undef : type[6][0];
function dc_motor_rated_output_rpm(type) = is_undef(type[6]) ? undef : type[6][1];

// The torque rated speed is quoted at. Stored in N m; this family's sheets publish kg.cm.
function dc_motor_rated_output_torque(type) = type[7];

function dc_motor_encoder(type) = type[8]; // [ppr, channels] of a fitted encoder, optional

// Counts per turn of the output shaft, every edge of every channel, through the reduction.
function dc_motor_encoder_counts_per_output_rev(type) =
  let (e = dc_motor_encoder(type), g = dc_motor_gearbox(type))
    is_undef(e) || is_undef(g) ? undef : e[0] * 2 * e[1] * gearbox_ratio(g);

// Shaft, gearbox and boss are drawn when present. The gearbox seats on the motor face and covers
// the shaft; shaft length is free length past the boss.
module dc_motor(type) {
  diameter = dc_motor_diameter(type);
  length = dc_motor_length(type);
  shaft = dc_motor_shaft(type);
  gearbox_type = dc_motor_gearbox(type);
  boss = dc_motor_boss(type);

  boss_length = is_undef(boss) ? 0 : boss[1];

  union() {
    color(light_grey)
      cylinder(d=diameter, h=length);

    if (!is_undef(boss))
      color(light_grey)
        translate([0, 0, length])
          cylinder(d=boss[0], h=boss[1]);

    if (!is_undef(shaft))
      color(medium_grey)
        translate([0, 0, length + boss_length])
          cylinder(d=shaft[0], h=shaft[1]);

    if (!is_undef(gearbox_type))
      translate([0, 0, length])
        gearbox(gearbox_type);
  }
}

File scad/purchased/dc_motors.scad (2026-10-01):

// parameters for physical realization of various dc motors
// DO NOT FORMAT THIS FILE, as it is manually spaced out for readability

include <gearboxes.scad>

// shaft and boss are the motor's own, with any gearbox removed. Speeds are at the OUTPUT, past
// the gearbox; an unqualified catalogue speed is a no-load speed, and rated is the speed at
// rated_out_torque (N m, converted from the sheets' kg.cm). encoder is [ppr, channels], ppr per
// channel at the motor shaft.

//                        ["name"              [dia,  len ], [shaft_d, shaft_l], gearbox,               [boss_d, boss_l], [screw_cdist, screw_d], [no_load_out_rpm, rated_out_rpm], rated_out_torque, encoder,  part_no]
// The motor on the bench; discontinued. The listing's top 12 V speed, taken as no-load.
motor_36gp_3530_5p18    = ["36GP-3530-5.18",   [34,   30  ], [2,       8      ], gearbox_36gp_3530_5p18,     [8,      3     ], undef,                  [1154,            undef        ], undef,  undef,   undef        ]; // discontinued, no number published
// E-S Motor 36D, RobotShop RM-ESMO-16Q, from the datasheet.
motor_36pg_3429_5p2     = ["36PG-3429-5.2",    [34,   29.4], [2,       8      ], gearbox_36pg_3429_5p2, [8,      3     ], undef,                  [1400,            950          ], 0.0637, undef,   "RM-ESMO-16Q"];
// E-S Motor 36D with encoder, RobotShop RM-ESMO-071, the drive for the next build. Six flying
// leads: M1/M2 and the encoder's GND, A, B, Vcc. len is the sheet's overall 57.
motor_36pg_555pm_14_en  = ["36PG-555PM-14-EN", [36,   57  ], [2,       8      ], gearbox_36pg_555pm_14, [8,      3     ], undef,                  [420,             320          ], 0.4903, [12, 2], "RM-ESMO-071"];
// bare motor supplied on the peri pump head, no part number, 12 V / 5 W, no published speed
motor_12v_5w            = ["12v_5w",           [27.5, 38  ], [2.3,     20     ], undef,                 [10,     3     ], [15.75,       2      ], undef,                            undef,  undef,   undef        ]; // arrives fitted to the pump head

// Two rows cannot be ordered (discontinued; arrives fitted to the pump head) and stay swept
// because they exist.
dc_motors = [motor_36gp_3530_5p18, motor_36pg_3429_5p2, motor_36pg_555pm_14_en, motor_12v_5w];

use <../utils/registries.scad>;
function dc_motor_by_name(name) = registry_by_name(dc_motors, name);

use <dc_motor.scad>

// example usage (open this file directly to preview)
// dc_motor(motor_36gp_3530_5p18);

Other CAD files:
models3d/ThermocoupleMountPrint.stl
models3d/MotorMountModel.FCStd
models3d/O2MountModel.FCStd
models3d/LidStencilPrint.stl
models3d/LidStencilModel.FCStd
models3d/ThermocoupleMountModel.FCStd
models3d/impellerModel.FCStd
models3d/PHMountModel.FCStd
models3d/O2MountPrint.stl
scad/assembly.scad
models3d/ImpellerPrint.stl
models3d/MotorMountPrint.stl
models3d/PHMountPrint.stl
models3d/Pump Stand Side.stl
models3d/Pump Stand Top.stl
printing/base.3mf
printing/base_mk3.3mf
printing/base_split_mk3.3mf
printing/base_v2_simple.3mf
printing/impeller.3mf
printing/impeller_PC.3mf
printing/impeller_PC_XL.3mf
printing/impeller_PP.3mf
printing/lid.3mf
printing/lid_PC_XL.3mf
printing/lid_PC_mk3.3mf
printing/motor_mount.3mf
printing/motor_mount_new_middle.3mf
printing/peri_pump_mount_NKP-DC-S10B_v1.3mf
printing/probe_clamp.3mf
printing/pump_side_mount.3mf
printing/ribs.3mf
printing/rod_spacers.3mf
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

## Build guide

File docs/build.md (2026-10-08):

# Building it

What you do with tools in your hands. The other documents say why the reactor is the shape it is;
this one says what to cut, what to print, in what order to put it together, and which numbers will
break something if you get them wrong.

**Numbers here come from one of three places, and it is worth knowing which.** Most are quoted from
the model's own echoes, and those are the authority — this document repeats them for the reference
build, `jar_10L_220x305`, the vessel the registry selects. Build a different jar and they move,
sometimes a lot: render `scad/bioreactor.scad` and read yours back. Some come from the notes on
[`purchased-parts.csv`](../purchased-parts.csv), which is where a bought part's tolerances live. A
few are worked out here, from the two — the torque band and the stiffness of the bolted stack are
the only ones that matter — and each of those says so where it appears.

---

## Nothing here has been built yet

This reactor has not been printed or assembled. Every number below is derived from the model, and
the model has never been contradicted by a part in someone's hand. That is a real limitation and it
is worth stating plainly rather than burying: a first build should expect to correct this document.

Three figures in particular are bands rather than measurements, and all three are on
[`TODO.md`](../TODO.md) waiting for a bench:

- the **sterile filter's pressure drop**, extrapolated from a comparable disc, and the largest single
  term in the gas budget
- the **jar's rim profile**, which everything sealing is measured against and which no one has
  calipered
- the **baffle's lean under load**, reported as a worst case that the model itself says is a worst
  case

Not every vessel takes every drive. `jar_1p5L_112x215` and `jar_1gal_155x251` cannot carry a
top-entry drive on their lids at any mount size — the mount overlaps the port flanges on the first,
and on the second the pH probe runs through the lower impeller, because in a 155 mm bore the port
circle and the impeller want the same radius — so both are built with no drive, and `jar_1p5L` also
takes the magnetic one. The builds that work are the sets in `scad/bioreactor.json`, and
`just check-builds` fails if one of them stops building. What each vessel cannot yet take, and why,
is on [`TODO.md`](../TODO.md).

---

## What you print

None of these appear on the purchase list, because a purchase list only knows about things you buy.
This is the part of the build nothing else will remind you about.

**From `head.scad`:**

- the **lid**, one piece — flange, plug, bearing pocket, insert holes, gasket recess, o-ring groove,
  and all twelve bayonet _lock_ halves. The locks are not optional detail: their channels are the
  walls of the lid's bores, so a lid exported without them is twelve plain holes that nothing locks
  into
- the **port pin halves**, one per port — tube ports for `air_in`, `air_out` and the dosing
  lines `dose_1` to `dose_3`; probe ports with their integral flex collets for DO and pH; a thermocouple port carrying
  an NPT mount
- a **blank port** for each bayonet size the lid uses — a pin with no bore, labelled `BLANK`, to
  close a port with nothing in it while cleaning, testing or servicing
- the **baffle ports and plates** — one plate per baffle port, each split into dovetailed pieces
- the **motor mount**, in three parts: base plate, face plate, middle stand
- **two impellers**
- the **sparger** — the arm, or the ring if the build names it (`sparger_name`; see
  [The sparger](#the-sparger))

**From `frame.scad`:** the base, the top base, **eight ribs** and **twelve rod spacers**. The ribs
are one part printed eight times, which took measuring rather than reading — each is rotated by a
multiple of 90° and bitten by the same lights cutout, and the exported meshes disagree because the
cut surface tessellates differently at each angle. Intersecting one with another turned to its angle
returns a whole rib, so it is one solid meshed two ways.

**The drive decides two of those lists.** `drive_name` in `bioreactor.scad` is `shaft` (above),
`magnetic` or `none`. Magnetic takes the motor mount and the impellers off the head's list, adds a
**bearing blank** in their place, and adds the **stir carrier** and the **hub cap** to the frame's,
and on `jar_1gal_155` and `jar_6p5gal` the **stir riser** too.
On the default lid the lid and the base are the same parts either way: the lid keeps its bearing pocket, bore and
inserts and the blank plugs them - its boss is the bearing's size, sealed by the pocket's own
o-ring, its pin fills the shaft bore, and its flange bolts to the four inserts with the mount's own
screws - and the base is slotted for the carrier whichever drive a build names, except on a jar
whose magnetic build stands on a riser, where the riser carries the slot. See
[The magnetic drive](#the-magnetic-drive).

`none` prints neither drive's parts: the gas is all that moves the culture, and the sparger is the
ring unless the build names the arm. Its lid is plain - no pocket, bore or inserts - which
`lid_center_name` sets: `bearing` for the convertible lid above, `plain` for this one, and `auto`
takes plain under `none` and bearing otherwise. A magnetic build states `plain` where the blank's
flange would not clear the ports, as `jar_1p5L_magnetic` and `jar_1gal_155_magnetic` do; that lid
cannot later take the shaft.

**Tools, printed once:** the three parts of the gasket cutter. The base is printed once for good —
it is the same for every gasket; the outer disc and inner plate follow the cut and are reprinted
when the vessel changes.

Food-grade clear PETG for anything in contact with the culture, grey PETG for structure. The
food-grade qualifier is a purchasing constraint, not a colour: a clear spool is not automatically
one, and the wetted parts are what the culture sits against for the length of a run.

### Two things about printing them

**The two impellers are mirror images, not the same part turned over.** Pumping direction follows
the blade's handedness and rotating a part cannot change it. They are two different STLs, and a pair
built from one file twice will pump the same way and not converge on the sparge ring.

**Export the motor mount from `head.scad`, not from `motor_mount.scad`.** That file will happily
build a mount, and the mount it builds does not match the holes the assembly drills in the lid. The
file says so itself.

The baffle plates are split so no piece is too slender to print standing:

```
baffle print: 2 pieces of 137.202 mm, tallest standing 160.202 mm against a 200 mm slenderness cap;
the dovetail leaves 4.2 mm of 10 crossing each joint, 0.074088 of the plate's second moment
```

A larger printer can pin `baffle_segments = 1` and print each plate whole, which is stiffer: the
joints already take 14 % of the tip deflection.

**The slide runs along the plate's width, and that is a load choice.** The swirl pushes on the
plate's face, so with the slide across the width that load bears on the dovetail's flanks and the
one free axis carries only vibration. A blind end registers the pieces; the butt faces meet, so
the 0.1 mm allowance is flank clearance only and the plate keeps its length. The neck — the only
material crossing the joint plane — is the parameter rather than the tail's depth, and a shallow
10° flare buys engagement without eating it.

**Two things about the joint are not modelled.** The first mode `head()` reports is the solid
plate's; the joints soften it by an amount not computed. And a 0.1 mm crevice at the joint sits in
the culture, in a vessel that is chemically sterilised rather than autoclaved — a cleaning
liability nothing here answers.

**That cap is about the part, not about your printer.** It used to be a literal 170, justified by
180 mm machines being "the small end of what anyone building this owns" — and no 180 mm machine was
ever going to build this reactor, so the number was measuring nothing. It is now a piece's height
against **three times its own section**: a brim as wide as the part on each side, which is why a
brim is worth printing on something this slender. On `jar_10L` the rule gives **205.07 mm**, and
the **printer ceiling clamps the cap to 200 mm** — the shortest registered build height less 10 —
so 200 is what the echo reports, against a 163 mm tallest piece.

The piece that binds is not the obvious one. The piece carrying the port stands on a **28.2 mm
flange**, which is a wide foot; a tip piece stands on the section alone and is half again as
slender for it. That section is **17.09 × 10 mm** — the widest plate the port's lock bore will
pass, not the 10.3454 mm this jar's sparge ring actually leaves — so the cap is a property of the
port and grades the same on every vessel.

`just export-parts` writes every one of these as its own STL, with a print list beside them, and
CGAL-renders each on the way past — so a part that is not a valid solid is caught there rather than
in a slicer. It measures each one too, and reports which registered printers take it. It covers the
reactor's own parts — the lid and everything hanging from it, and the frame's base, top base, ribs
and rod spacers — which comes to **49 pieces across 25 distinct parts** on `jar_10L_220x305`.

**A build is a parameter set in `scad/bioreactor.json`**: a vessel and whatever it designates.
`just export-parts jar_10L_magnetic` exports that one to `output/jar_10L_magnetic/`, and the print
list opens with the model's own statement of what it is (vessel, drive, fill, every designation
not left `auto`). To look at one part while working on it, `just export-part frame_base
jar_10L_magnetic` renders that row alone in a few seconds and writes no list.

**`just export-parts` with no build exports every registered build, by vessel**, to `build/`:

```
build/jar_10L_220x305/
  common/     the frame, the gasket cutter, the lid, the ports, the sparger
  stirred/    the motor mount and the impellers
  magnetic/   the stir carrier, the hub cap and the bearing blank
```

`common/` is what every registered build of that vessel prints the same - the same part, judged by
its geometry rather than its name, and not one drive's own - so it is printed once, and the type's
folder adds what makes it that build. A vessel with one registered build still splits its drive's
own parts out. Each distinct part renders once, and each vessel's folder is replaced whole, so
what is there is what the model prints now.

It renders the parts in parallel, every core at once, so the whole list takes about as long as the
lid alone - a minute and a half here, a few on a small runner.

**Without OpenSCAD:** the Export workflow on GitHub runs the same export on demand and on every
tag, one job per build, and leaves the STLs and the print list as a downloadable artifact
(`stl-<build>`) on the run. It is also the only place the parts that print are CGAL-checked in CI —
`just test` covers the entry files' previews, not the manifests.

It is not everything in this repo that gets printed. The **cart**, the **electronics stand**, the
**bottle holder** and the **peri pump mount** each render from a file of their own and are on no
manifest, so they appear on no print list. `just check-parts` holds the record of that rather than
letting it go unnoticed, and giving them manifests is on [`TODO.md`](../TODO.md).

`bioreactor.scad` reports the printer
answer independently, off the geometry rather than the meshes; the two agreeing is the check that
nothing has fallen off a manifest.

**What you need to own.** Three parts are a **257.6 mm disc** — the lid, and the frame's base and
top base — and they are the widest things in the build by a long way. A disc has the same width at
every angle, so it cannot be turned to fit a narrow bed: what your printer needs is `min(X, Y)` of
at least 257.6.

`scad/bioreactor.scad` reports this on every render, against the machines registered in
[`scad/purchased/printers.scad`](../scad/purchased/printers.scad). Today that is the **Prusa CORE
One L**, the **Bambu H2D**, the **Sovol SV08**, a **Voron 2.4 350** and the **Prusa XL**.

What misses, and by how little, is worth knowing. A **Bambu X1C** is 256 — short by **1.6 mm**. A
**Voron 250** is short by 7.6. A **Prusa CORE One** is 250 × 220 and cannot do it at any margin,
because the jar alone is 220 mm across and the lid has to overhang the glass to carry its bolts.
The lid was briefly trimmed to 252 to reach the X1C; the frame's bases are 257.6 too and its wall
is set by the rod bosses, so that bought nothing and was undone.

---

## What you cut

| Stock | Cut | Yield |
| --- | --- | --- |
| M8 threaded rod, DIN 975 A2 | **4 × 322 mm** | buy 1500 mm or more |
| 316 SS tube 4 × 0.5 mm, `50415K21` | **1 × 251.4 + 5 × 188.2 mm** | 1192.3 mm from a 2000 mm length, 807.7 mm spare |
| EPDM sheet 1/16 in 60A, `8525T65`  | **142.2 × 158.2 mm** per lid | 1 per 304.8 mm sheet |

**The rod length follows the jar, not the design.** 322 mm is `jar_10L`; it is 214 mm on
`jar_1gal_180` and 487 on `jar_6p5gal`. It is derived as vessel 305 + flange 8 + nut 6.5 + 2.5 mm
left proud of the top nut, so a different vessel height moves it directly.

**Deburr the tube bore after cutting, and treat that as a step rather than a nicety.** A wheel
cutter rolls a 0.5 mm wall inward at the cut, and the riser's bore is only 3 mm — so the restriction
lands exactly where gas enters. The registered tool is a NOGA RC1000, whose minimum bore is not
published; check its blade actually reaches 3 mm before relying on it. A round needle file does the
same job on two cuts. A jeweller's saw in a mitre jig avoids the problem instead of correcting it,
because a saw does not roll the wall in the first place.

Cut the rim gasket with the printed cutter rather than by hand. Everything happens on the base,
which is the cutting surface, carries the nuts and is what both stages screw to, so nothing has to
be lined up on a board by eye.

1. **Three M4 nuts into the channels** on the base's underside, and one into the hex pocket at its
   centre. They cannot turn, and they slide along their channels, which is what lets one base serve
   every gasket size.
2. **First cut.** Lay the sheet on the base, put the outer disc on it, and run a screw through the
   disc's centre into the central nut. Cut round the disc. The screw pierces the sheet at its
   centre, which is waste — the inner cut removes it.
3. **Second cut.** Leave a short screw standing in the centre and drop the blank over it, or just
   lay the blank on the base. Lower the inner plate onto it: the counterbore's mouth is flared, so
   it shepherds the blank into its seat as it comes down. Run the three clamp screws through the
   plate, through the base's slots, into the nuts. Cut down the bore.

   The base has two rings of slots. A plate reaches whichever one clears its own blank — the inner
   ring for the small jars, the outer for the large — so the nuts move to match the plate you
   printed, and the ring the plate does not use stays clear of every cut.

The plate stands `grip` (0.4 mm) proud of its seat, so it closes on rubber and pinches the blank
rather than resting on the base. The concentricity of the finished ring is a printed counterbore
rather than your hand.

> Earlier versions had no base: the blank was loaded into an upturned plate and the pair turned
> over onto a board, which is awkward and drops the blank. The flare at the counterbore's mouth is
> what removes that step, and the base is what removes the board.

---

## Fits you make

Most of the fits in this reactor are bought. These are the ones you create at the bench, and each
one has a number that decides whether it works.

**The bearing is a press fit — heat the race and chill the shaft.** That is what McMaster specify,
not a workaround for a wrong hole. The shaft is 7.995–8 mm in an 8 mm bore, so the fit runs from
0.007 mm interference to 0.005 mm clearance; the pocket in the lid is 22.2 mm for a 22 mm outside
diameter. The joint feeling tight on assembly is the intended condition.

> **The bearing is the weak link against the sterilant.** This reactor is chemically sterilised
> rather than autoclaved: 7.5 % hydrogen peroxide for everything but the pH and DO probes, and bleach
> or chlorite only ever on the glass vessel. 440C is not rated for bleach and Buna-N is poor against
> oxidisers, peroxide among them; the shaft is 316 for that reason. The bearing sits in a blind lid
> pocket and is not submerged — keep it that way, and keep it out of the vessel's bleach step.

**Heat-set the four M4 inserts into the lid from the mount face.** 4.7 mm of insert into a 5.6 mm
hole, with 13.25 mm of lid left beneath them. The inserts go in once and stay; the M4 × 8 screws
into them come out every time the mount does. The insert only offers 4.7 mm of thread, so a longer
screw bottoms out instead of clamping, and the screw is 18-8 into 18-8 — take care not to round the
socket.

**The impeller bore is a slip fit, and the set screws are what locate it.** The bore is 8.4 mm
straight through on an 8 mm shaft — 0.4 to 0.405 mm of slack before print shrinkage — so an
impeller slides to its height and is fixed there. It used to taper to the shaft's nominal over the
hub's height, which is a fit you drive on: tolerable with one impeller sitting at the bottom of
the shaft, wrong with two that each have a height to hold. Open the bore with a reamer or a drill
if your printer closes it up; `head()` reports the slack it was cut for.

**The impeller set screws cut their own thread.** The hole is printed at the 3.3 mm tap size and no
thread is modelled; printed holes come out undersize, so expect to open one. Two per impeller at 0
and 120°, 5.8 mm of thread through the 8 mm collar above the blades. They are cup-point on purpose:
they bite the shaft rather than relying on friction, which is all that holds the impeller once the
bore slides.

**The o-rings go in four different ways, and only one of them is stretched.**

| Seal | How it seats |
| --- | --- |
| Lid plug, `AS568-160` | **stretched 3.67 %** onto a groove cut from the jar's bore |
| Port face seals, 12 of them | seated in a gland cut to fit the ring, no stretch |
| Riser rod seals, `8785N364` ×5 | **0 % stretch** — the ring's ID _is_ the 4 mm tube |
| Bearing rim seal, `8785N382` | **0 % stretch** — the ring's ID _is_ the 22 mm bearing |

**The bearing seal goes in before the bearing.** Drop the 22×1.5 down the pocket and let it expand
into the groove at mid-depth, then press the bearing past it. It seals on the bearing's **outer
race**, which does not turn — the inner race does, and on a 608 both race faces are flush, so a
gasket under the bearing would be clamped against a rotating steel face. Nothing seats _on_ the
pocket floor: the bearing still bottoms there.

The rod seals go into an enclosed groove just above the lid's **inner** face, and they go in
**before** the tubes pass through. That face is inaccessible once the lid is on the jar. There is
one per tube port — five on the full lid, three on the six-port jars.

**The silicone sits differently at every joint, and the risky ones are all downstream.** One bore,
3/16 in ID, covers the whole run from the meter to the ring: **native** on the check valve's barb,
**stretched 33 %** onto the sterile filter's 1/4 in step, and **0.76 mm loose** over the 4 mm riser,
which a worm clamp closes. Watch the filter joints: silicone creeps,
and that joint is the sterile barrier. A leak upstream of the rotameter only costs flow you then
dial back in; a leak downstream means the vessel gets less than the meter claims and every vvm
figure in [`agitation.md`](agitation.md) is wrong by that much. All four of the risky joints — the
check valve twice, the filter twice — are downstream.

---

## The magnetic drive

A PC fan in a printed carrier hung in the base's bore, two magnets in a cap on its hub, and a PTFE
stir bar on the jar's punt inside. Nothing passes through the lid. What the model picks and where it
puts it:

```
stir drive: fan80x25 in a 164.6 mm carrier 36.75 mm tall, its top 0 mm under
the landing plane, hung on its ear 8 mm off the bottom face; the fan is turned 55 deg
to put a flat on the slot's bearing, and the lead leaves its 8 mm notch there for the
14.65 mm slot at 145 deg
fan joint: 4 x M4 x 40 mm down through the fan into nuts in 4.2 mm hex pockets at the
carrier's bottom face, 7.55 mm of carrier over them; the head stands 2.2 mm on the
fan, 3.48992 mm under the glass
fan joint, head down: an M4 x 40 mm cap screw up from the pocket to a nut on the fan
stands 4.25 mm over that nut, 1.76008 mm into it - shorten the screw, or build it the
other way up
stir magnets: 2 x MAG5x8 on the 40 mm hub at 28 mm pitch, faces 1.24242 mm under the
punt and 6.24242 mm from the floor inside
stir bar: 38x8 centred on the 30 mm punt plateau, overhanging it by 4 mm each end;
sweeps r 19 under the sparge arm, 55.49 mm over it and the baffles at r 51.3273; the
sparger is still placed on the shaft drive's impeller
```

**The fan is picked by rule, not named.** Of NopSCADlib's fans, the one with the widest hub whose
corners clear the carrier's pocket and whose depth fits under the jar with the joint's own depth
reserved; the thinnest of that hub. The hub is the sort key because it is what the magnets are
carried on, and a wider frame around a smaller hub buys nothing. An 80 × 25 on `jar_10L` and
`jar_1gal_180`, a 40 × 11 on `jar_1p5L`, and on a riser a 60 × 25 on `jar_1gal_155` and a
120 × 25 on `jar_6p5gal`. The magnets
and the bar are named (`stir_magnet_name`, `stir_bar_name`), because a bench usually has some: the
defaults are two Ø8 × 5 discs and a 38 mm bar, and the other registered sizes are in
`purchased/magnets.scad` and `purchased/stir_bars.scad`.

**The floor under the jar is sunk for that fan, up to a point.** The frame reaches below the jar by
whatever the light stack overshoots its height by — an accident of which light the jar took, which
left the drive at its mercy. The floor now takes the deeper of that and what the fan and the magnets
need, so a jar whose light happens to be short still gets a drive. `jar_1p5L` is 3.77 mm deeper for
it and gains a carrier. `carrier_floor_lift_max` (10 mm) is how far that goes: past it the base
would be mostly added floor. The floor does not depend on which drive a build names, so the base is
still one print for either.

**Past that limit the magnetic build stands on a riser.** `jar_1gal_155` wants 36 mm more than its
light leaves and `jar_6p5gal` 35, so their bases keep the light's floor and a magnetic build of
either adds `frame_stir_riser`, which makes up the rest under the whole frame:

```
stir riser: 36 mm under the base, which keeps the light's 4 mm floor; walls at r [50.15,
63.65, 82.25, 94.95], keyed into every light's cord notch
```

It is walls only, 3 mm (`riser_wall`), so it prints as it stands with nothing to bridge but the
lead's doorways. Four rings: one round the carrier at the base's own bore; one under the circle the
jar lands on, since the floor ring over it is 4 mm on `jar_1gal_155` and would otherwise span; one
under the lights' middle, which holds them at the base's underside as the bench would; and one
round the base's edge, so the reactor stands on the base's full width. Four spokes on the quadrant
lines tie them. The carrier hangs in it exactly as in a deep base: a block on its ring carries the
same groove and ear notch, and the groove runs on out through the other rings as the lead's
doorway.

It locates in the base's cord notches, all twelve: in each, from the seat's face to the edge, a key
fills the notch less the 0.3 mm a light keeps in its seat, so it centres on the base as closely as a
light sits its seat and leaves every seat clear. **The lights' cords leave from the top**, against
the top base, which is also where a light seats best. The reactor stands 36 mm taller for it, and a
build under any other drive stands on the bench.

1. Stand the riser on the bench, drop the carrier in with its ear down the notch, and lead the
   wire out through the doorway.
2. Fit the lights into the frame, cords up, then lower the frame onto the riser with a key in every
   cord notch.

The carrier's ear stands 23.8 mm off the bench, so a riser has to be at least that tall to hold it
under the base. A drive wanting between 10 and that over the light's floor fits neither the base
nor a riser, and the model says so; no registered jar is in that band.

**How high the carrier hangs is set by the magnets, not the fan.** Their faces are held
`stir_magnet_glass_clearance` (1 mm) under the jar's punt, at the magnets' outer edge where the cone
comes lowest, and the carrier's top follows down from there — never above the plane the jar lands
on. That is what "faces 1 mm under the punt and 6 mm from the floor inside" is: 1 mm of air and 5 of
glass to the culture, with the bar's axis 4 mm above that.

That ceiling is why a deeper floor does not help every jar. Where the punt rises further than the
magnets and their cap need, the carrier stops at the landing plane and the cap grows instead: a solid
floor under the magnets, up into the punt's void, until either the magnets reach their clearance or
the cap's rim reaches its own. On `jar_10L` the rim binds first, so the cap is 8.39 mm tall and the
magnets sit 1.24 mm under the punt. On `jar_6p5gal` the punt rises 15 mm at the magnets and the cap
grows 8 mm to reach 1 mm, but its 12 mm wall still puts them 13 mm from the culture against 4-6 mm
on every other jar. Floor depth is not that jar's problem.

**Assembly, in the order the parts allow:**

1. **Print the carrier pocket up, as it is modelled** — there is nothing to support: it is solid
   under the fan, every wall is vertical and the ear's wedge slopes upward.
2. **Four nuts into the hex pockets in the bottom face**, then the **fan into the pocket from
   above**, hub up, with its lead on the side the pocket wall is cut down — that side faces the
   base's slot. Four M4 × 40 screws down through the fan's own corner holes into those nuts: one
   driver, from above, and the nuts cannot turn. The fan is bolted rather than screwed into its
   own plastic, so it comes apart as many times as you like. The lead lies in the 8 mm cut above
   the 3 mm seat, wherever it leaves the fan, and drops down the notch in the middle of that side.
   The heads stand 2.2 mm on the fan with 3.49 mm to the glass; the nuts and the last 4 mm of
   thread sit under the carrier, in the 8 mm the ear holds it clear by.

   The pocket is cut to the larger of an M4 nut and an M4 cap head, so **the joint also runs the
   other way up** — cap screw up from the pocket, nut on the fan's face, hex key from below and a
   spanner on top. Nothing about the print changes. Whether it closes does change with the jar,
   because the screw comes in 5 mm steps and the remainder stands over the nut: on `jar_10L` an
   M4 × 40 is 1.76 mm into the glass, and on `jar_1gal_180` an M4 × 35 is 0.59 mm into it, so
   either would have to be shortened. The `fan joint, head down` echo gives that number for the build
   in front of you. Build it heads up unless you have a reason not to.

3. **Magnets into the cap**, opposite poles up: a bar follows a north and a south, and two norths
   hold nothing. Press-fit pockets (0.2 mm on the diameter); a drop of adhesive if they are loose.
   Glue the cap to the hub's face, or stick it with double-sided foam tape, centred — it is a disc
   rather than a skirt because a skirt would foul the blade roots.
4. **Carrier into the bore from above, before the jar.** Turn it until the ear finds the notch at
   the slot's light position and let it down: the ear lands on the two shoulders beside the wire
   groove and the carrier hangs from them, 8 mm clear of whatever the frame stands on. The lead
   comes down the notch between the ear's two legs and straight into the groove, which joins the
   light cord notch already cut through the wall. On a riser the carrier goes into the riser
   instead, before the frame is set on it, and the groove is the riser's doorway out.
5. **Bar into the jar, jar into the base.** The bar sits centred on the punt plateau; the magnets
   find it through the glass.
6. **Blank onto the lid.** The 22×1.5 ring goes in the pocket's groove as it would for the bearing;
   the blank's boss pushes past it, the pin down the bore, and four M4 screws into the inserts.

**What the base gives up for this:** one T-shaped slot at an empty light position — the cord
notch's own profile carried across the floor ring to the bore, and above it a notch 3 mm wider each
side, open at the top, that stops 8 mm short of where the jar lands. Nothing else moves, and the
slot is cut under the shaft drive too, so a base printed today takes either. A base whose magnetic
build stands on a riser gives up nothing: the slot is the riser's.

**Three things it buys** that are on no purchase list yet: the fan, the magnets and the bar. Any of
the size does, which is why none has a part number; `check-bom` says so in its header.

**What it does not do.** The sparger, the baffles and the DO probe's lean are still sized and
placed on the shaft drive's impeller — that geometry is their basis and stays. The echo says so.
And nothing here models the coupling: how much torque two Ø8 discs hand a bar through 6 mm is a
bench measurement, which is why the fan and magnet sizes are parameters rather than answers.

## The sparger

Two spargers, one build parameter: `sparger_name` is `cap` — an **arm** — or `ring`, and `auto` is
the arm. The ring is what runs under no drive and the airlift; the shaft and magnetic builds run
the arm. Both hang off the same riser from the `air_in` port, and the other four tubes stay whichever
is fitted — they are the dosing and vent lines, and under the arm they simply have nothing to
socket into.

```
sparge arm: from the air inlet's riser at r 56.5 in to r 9, 66.9536 mm off the floor,
10 mm under the lower impeller's blades, 5 mm short of the shaft; at 0.5 vvm that is
4.08517 L/min
sparge arm: 3 holes of 3 mm along 31.9 mm at 3.54444 hole diameters, 3.21074 m/s each;
bubbles 5.09817 mm at formation, 981.337 a second; the 4 mm bore carries 5.41813 m/s,
open area ratio 1.6875
```

**The arm is the ring's feed without the ring**: the same socket the riser drops into, the same
elbow, and one straight run turned inward to end 5 mm short of the shaft, holes drilled down so the
bubbles rise into the lower impeller. It sits 10 mm under that impeller's blades, which is where a
sparger goes in the stirred-tank literature; the ring sat between the impellers on Birch & Ahmed's
argument, and that argument stays with the ring. Same 3 mm holes as the ring, same anti-fouling
reason; the count follows the arm's length at the pitch floor.

**With no drive the ring goes to the floor.** Between the impellers is only a place when there are
impellers; under `drive_name = "none"` the ring's underside sits `sparge_ring_floor_gap` (10 mm)
over the highest glass beneath it, so the column is sparged from the bottom. The supports lengthen
to match - on `jar_1p5L` that moves their stock from a 500 mm length to a 1000 mm one.

**How the riser is held.** Every socket is bored 0.2 mm over the 4 mm tube — a slip fit, since a
printed bore at the tube's own size is a press fit and the ring's five blind sockets cannot take
one. Every socket is 12 mm deep. The ring rests on its six tubes and needs nothing more. The arm
hangs on one, so its socket carries a boss, and the same M4×6 316 set screw that plugs the ring's
ends self-taps into a pilot in that boss and bites the tube by 3 mm: seat the arm, point it at the
shaft, and drive the screw. The arm's end is open through a pilot like the ring's, so a brush
passes, and a second of those screws plugs it.

**The baffles keep the ring's width under either sparger**, so one set of plates prints once. The
arm would let them widen from 10.35 to 14.5 mm — but at 2 mm nominal to the impeller against the
2.28 mm of lean the port coupling allows, a 14.5 mm plate can touch the blades. Widening them is
its own decision, and `baffle_impeller_clearance` is the number to raise first.

**Check-holes covers whichever is built.** The head's hole probes used to be echoed in the part's
own frame while the mesh sat 170 mm lower, so they landed in empty space and passed without
testing anything; they are placed with the part now, for the ring and the arm both.

## The airlift's draft tube

`drive_name = "airlift"` adds one printed part, `draft_tube`: a plain tube on three feet, standing on
the jar's floor round everything that hangs from the lid. The gas rises inside it and the culture
comes down outside. Nothing holds it but the ring.

```
draft tube: 80.7 mm bore, 84.7 mm outside, 151.501 mm long from 12.3179 to 163.819 mm off the
floor, on 3 feet of 10.9608 mm; 1.4 mm each side through the mouth, and the ring inside it keeps
1.25 mm to its wall, so it shifts up to 1.25 mm
```

1. **Print it in clear PETG, feet down.** It is a straight wall with no overhang; each foot meets
   it through a 6 mm fillet either side (`draft_tube_foot_fillet`), so the corner does not crack.
   An opaque tube makes its core a place the cells only pass through in the dark.
2. **Lower it into the jar first**, feet down and square to the mouth: it passes with 1.4 mm each
   side on both jars, so it goes in straight or not at all.
3. **Centre it by hand**, reaching down its own bore. Standing loose it can sit several millimetres
   off centre on `jar_1p5L` and more on `jar_1gal_155`, and the ring has 1.25 mm to find its top.
4. **Then lower the lid.** The ring goes down inside the tube and ends inside its feet or its wall,
   which holds it there. Everything else hanging from the lid ends inside it.

**It can move.** The ring stops it 1.25 mm off centre where it sits inside the wall, as on
`jar_1p5L`; on `jar_1gal_155` the ring sits among the feet and the tube can shift 2.5 mm. `head()`
checks the probes against the tube shifted that far, and the tightest is `jar_1p5L`'s collets at
0.75 mm. The DO probe hangs straight under the airlift.

## Putting the lid together

The order is forced by geometry, not preference.

1. **Ports into the lid first.** The lock half of every bayonet is printed as part of the lid; the
   pin half is the cartridge that carries the flange, the seal and whatever hangs into the vessel.
   It drops in from outside and turns to lock. Two catch pockets in each flange are there for
   pliers.
2. **Everything that hangs below a port must pass the lock's bore on the way in** — that is what
   sets the baffle plate's width, and the model asserts it.
3. **Then the lid goes onto the jar**, and everything hanging from it passes down through the mouth
   — so _every part of the assembly is level with the mouth at some moment on the way down_. What
   matters is the widest the assembly ever gets, not where it finishes. On `jar_10L` the DO probe's
   collet is the binding part, reaching 70.78 mm against a 71.1 mm mouth — **0.32 mm to spare**.
4. **The probes go in last**, down through the bayonet's bore into the collet. They never pass the
   mouth at all, which is why their length is not part of the clearance above.

### Two ways to assemble it wrong that nothing will catch

**The ring's sockets look identical from above.** (The arm has one socket, and this does not
arise.) The feed socket is an **octagon** and the
support sockets are **round**, and that is the only thing telling them apart, because you cannot see
inside a socket at the bottom of a jar. Get it wrong and the gas goes down a capped tube and
straight back out its own vent hole into the headspace — while the rotameter reads flow and the
culture gets nothing.

**And the tell is weaker than it was, which is worth knowing before you rely on it.** The feed
socket used to be a hexagon and is now the tube's own section, so it follows the tube instead of
being a second size — a good change for the joint, and a worse one for telling sockets apart. Both
sockets are the same 6.4 mm across the flats; the octagon's corners stand only **0.264 mm** proud of
the circle, where a hexagon's stood 0.49. Count the facets or feel for the corners rather than
glancing.

**The ports are labelled by function for the same reason.** `air_in` and `air_out` have the same
bore, so marking them by bore alone put `Ø6` on both. A gas line on the wrong one vents into the
headspace; a dosing line on the wrong one puts acid where base should go. The marks read
`AIR IN Ø4.4`, `DOSE 2 Ø4.4`, and which dose carries what is yours to record. Baffle ports are marked with the length of plate they carry.

**Every tube port bores the same Ø4.4 now**, because every one of them passes the same 4 mm riser,
so the bore on those marks tells you nothing and the function name is carrying all of it. Read the
word, not the number.

The sparge ring itself cannot be installed rotated, and it is better keyed than it was: it now
carries a socket under every tube port — six on the full lid at 0, 180, 210, 240, 300 and 330° — and
that pattern is irregular enough that only one rotation puts them all under ports. On the six-port
jars it is three.

### Drilling the support tubes

Every tube port but `air_in` takes a support tube: capped where it meets the ring, and doing its job
through a hole you drill. Four of them on the twelve-port lid, two on the six-port jars. The model is
the only thing that can dimension that hole, and it does:

```
sparge support drilling: a support tube vents through a hole drilled between
37.9375 and 88.4342 mm from its TOP end - past the lid's inner face, short of
the culture. Nearer the first number is better; the headspace is there for foam
and foam finds the lowest hole. A tube meant to discharge INTO the culture
instead is drilled past the second.
```

**Which end of that window depends on the port.** `air_out` is the exhaust and wants the first
number — a vent belongs in the headspace. The dosing lines discharge into the culture, so
they are drilled past the second, and low is better: the dose lands where the impeller will carry it
away, and the tube below the hole is a dead leg that keeps whatever it is given.

**Only `air_out`'s hole has a size to meet**, and the model prices it rather than saying it is the
exhaust path and leaving it there:

```
gas exhaust slot: a slot of the tube's own 7.06858 mm2 bore costs 154.633 Pa at
4.08517 L/min, and the tube above it 23.517-54.8192 Pa over the 37.9375-88.4342 mm
drilling window, together 2.4985-2.93751% of the 7130.28 Pa the exhaust has to
spend; file past 1.04095 mm2 (a 1.15125 mm round hole), which the bore clears
6.7905x over
```

**On this jar the floor is about 1.04 mm², which is a Ø1.15 mm hole** — a slot roughly 2.2 × 0.5 mm.
A normal file cut clears it nearly seven times over, and it is _not_ too small to miss: a shallow pass that
only just breaks the 0.5 mm wall over a couple of millimetres lands on the limit. Cut it, then hold
the tube up to the light and look through the hole before it goes in.

**Read the floor off your own render rather than off this page.** It moves with the jar, because it
is set by the headroom that jar's gas line has left: 1.041 mm² here against 0.288 mm² on
`jar_1gal_180x197`. And on `jar_6p5gal_305x470` there is no floor to quote at all — that build
cannot hold the top of its own aeration band, so the echo says so instead of printing a number.

That 7130.28 Pa is the same pressure the throttle is currently giving away, and the same headroom an
outlet filter would have to fit inside - so what the slot spends comes off both. The slot and the
tube are already in the line the pump is priced against, at the long end of the drilling window; an
outlet filter, once one is named, joins them there. The three dosing holes meter nothing and need
no size.

Measured from the **top** end, because that is the end you can reach with the tube in your hand.

---

## Closing the lid, and the number that cracks the jar

**This joint is limited by the glass, not by the fastener, and nothing about the hardware says so.**

Twelve posts hold the lid down on a 239 mm circle, 62.6 mm apart: **eight M8 bolts and four M8 tie
rods**, the rods occupying every third position. The bolts' heads bear under the top base; the rods
run the full height of the frame from the lower base. All twelve are tightened by a **nut sitting on
top of the lid flange**, so the operation is the same at every post.

```
joint load: 4212.27 N of gasket seating over 12 posts = 351.023 N each, on M8
bolts and M8 rods
lid lip: crowned on a 3.5 mm arc standing 2 mm proud of the wall - no flat to
seat on, so the gasket covers the lip and the crown sinks 0.396875 mm into it;
8 mm of gasket, 3.23766 mm of contact
lid gasket load: 3.23766 mm of contact, 4212.27 N to hold 25% squeeze,
2.77566 MPa on the glass
```

**351.0 N per post.** An M8 A2-70 proof load is about 16.5 kN, so the joint runs at **2.1 % of
proof** — the fastener is nowhere near being the limit. A published tightening torque for the same
bolt is 20–24 N·m. This joint wants something near **0.6**. Torque one of these to fastener spec and
you put roughly forty times the intended load onto a soda-lime jar.

### Do not reach for a torque wrench

Torque only ever reaches preload through a friction coefficient, and here you cannot know it. Across
the 0.20–0.30 that an unlubricated stainless nut plausibly spans, 351.0 N is **0.56 to 0.84 N·m** —
a 40 % band from the friction assumption alone. 18-8 galls, which is exactly what makes that
coefficient unpredictable, and 0.7 N·m is below the bottom of most torque wrenches anyway.

### Turn the nut instead

```
joint tightening: 114.3 deg past snug on each of the 12 nuts (0.396875 mm of gasket
travel on a 1.25 mm pitch); the printed flange creeps, so go back to them
```

A turn is geometry. The 1/16 in gasket is 1.5875 mm, 25 % squeeze is 0.3969 mm of travel, and an
M8 × 1.25 thread converts that to **114°**. No modulus and no friction enter it.

The rest of the stack barely moves: at 351.0 N an M8 bolt stretches 0.0010 mm over its 20.4 mm grip
and a rod 0.0005 mm over the 10.4 mm between its top-base nut and its lid nut — under 0.3 % of the
gasket's travel either way. The printed flange is the soft part, and it is the one number in this
section without a source: roughly 0.02 mm under a nut face, from PETG's modulus and a nut's bearing
area, which is an estimate and not a measurement. So:

> **Snug, then a third of a turn.** 120° is 114° for the gasket plus a little for the plastic, and it
> is a mark you can see on a nut where 114° is not.

Snug is where the flange stops moving under hand pressure on a short key.

**Pattern.** Bring all twelve to snug first, working across the circle rather than around it, then
take them to a third of a turn in the same order in two passes. A gasket squeezed unevenly seals at
its tightest point and leaks opposite it, and glass is unforgiving of being loaded on one side.

**Then go back to them.** PETG creeps under sustained load, and the flange, the top base and the
plastic under twelve nut faces are all in this load path. Re-check after a few hours and again after
the first run.

### Two things not to do

**Do not tighten until the flange meets the glass.** The recess is 1.19 mm deep for a 1.5875 mm
sheet, so at the design squeeze the gasket is nominally flush and the flange nominally touches. It
cannot actually get there: the recess holds three quarters of the rubber's section and elastomer is
near enough incompressible, so the last quarter has to escape sideways first. Flange-on-glass is
_past_ the design point, not at it.

**And on every jar but the 6.5 gallon there is no land to stop you.** Those lips are crowned, so the
flange has nothing to bottom on and the turn is the only thing setting the squeeze — which is why
this section instructs a turn rather than a torque, and why over-tightening is a real possibility
rather than a theoretical one. Count the turn.

**Do not substitute a harder gasket without re-deriving the joint.** 60A durometer is what sets the
ASME VIII-1 gasket factor m = 0.5, and that is what gives twelve posts. At 75A or harder the same
lid wants sixteen.

### How good is 351.0 N?

Not very, and the model says so. `elastomer_shape_factor()` is the free-bulge form — it assumes both
edges of the pad can spread, and the recess walls are exactly where they cannot. The modulus behind
it is correlated from hardness rather than measured. So 351.0 N and 2.78 MPa are figures for judging
a design, not for cutting a part to, and `elastomer.scad` says as much at the top of the file.

**The turn is the more robust of the two**, which is why it is the instruction. It comes from the
gasket's thickness and the thread's pitch — neither of which is a correlation.

---

## The gas line

Order matters, and two of the joints are ordered for reasons that are not obvious.

```
pump ──3/8 in── reducer ──1/4 in── reducer ──1/8 in── METERING VALVE ──
      rotameter ──3/16 in silicone── check valve ── STERILE FILTER ── riser
```

**The metering valve goes upstream of the rotameter.** The meter is calibrated at 14.7 psia, and
putting the throttle ahead of it means the meter only ever sees downstream line loss — which is what
makes the correction 0.7 % instead of something that matters.

**The rotameter's two adapters are deliberately different sizes**, 1/8 in in and 3/16 in out, so the
line steps up inside the meter's own bore rather than through a coupler. One less joint.

**The sterile filter is the boundary.** Everything downstream of it is inside the sterile envelope
and is platinum-cure silicone; everything upstream can be PVC or polyurethane, and the barbed
fittings on that side are rated for firm line rather than silicone.

**One clamp size closes all fourteen joints.** `5011T141` is an SAE 4 on a 5/16 in band — 5.6 to
15.875 mm — which at the 1/16 in wall these bores are sold in reaches under the 1/8 in line's
6.35 mm outside and over the 3/8 in line's 12.70. The band width is not a free choice: it is what
`sparge_riser_proud` in `head.scad` is derived from, and the next band up is 12.70 mm, which would
leave 2.3 mm of lead-in on a tube that stands 14.94 mm proud.

**The joint that can escape the range is the largest, and it does not escape by a little.** Buy the
3/8 in run in a 1/8 in wall and it measures **15.875 mm** against a clamp whose limit is **15.875** —
the same number twice, on a clamp wound out to its last thread. Buy that run in 1/16 or 3/32 in wall
and the problem does not arise.

They are 316 in both halves, which is why they are rated to 7.5 in.-lbs and not 10: an austenitic
screw in an austenitic housing galls. Snug them with the 1/4 in nut driver and stop — a wrench will
strip one, and these get opened again at every filter change.

The check valve exists to stop culture siphoning back into the pump when it stops. It is not
optional.

**Nothing filters the way out, and fitting the obvious part would cost you the top of the band.**
A bioreactor normally filters the air in _and_ out. This one filters the inlet and vents the
headspace through a support tube's bore into the room, so the 0.2 µm filter guards one direction of
two. The tempting fix is a second `1594522` — the filter is sold in tens, so it looks free.

It is not. An outlet filter does not sit between the pump and the sparge holes, but it raises the
headspace those holes discharge into, and the gas has to beat that too. A second identical filter
puts the line at **32.3 kPa** against a pump that dead-heads at **27** — the reactor would settle at
**3.17 L/min**, and 0.5 vvm would stop being a setting it can hold. `head()` reports the budget:
an outlet filter may cost at most **1.7454 kPa per L/min**, which is 50.6 % of what the inlet one
does, so it wants roughly **twice the membrane area** rather than the same part again. The vent slot
and the tube above it are already priced into the line, so that budget is net of them.

Two numbers behind that are worth knowing. The pump's real ceiling on this line is **5.80 L/min**,
not the 21.3 that a back pressure held at the design point suggests — the filter is linear in flow, so
asking for more raises the line. And the inlet filter's own slope is still extrapolated rather than
measured, so the budget moves with it: measure that first, and this number follows.

---

## The exhaust condenser

Not on the lid's lists yet: each variant prints from its own file, `custom/condenser_cold_finger.scad`
or `custom/condenser_coil.scad`, and each part is exported in the orientation it prints in. See
`TODO.md` for what the prints still have to prove.

**Print the bodies to hold gas, and anything that holds water to hold water.** A condenser body is
the exhaust path: gas that leaks through its wall bypasses the cold and carries water out with it.
The cold finger's flow insert is the only wall between coolant and the gas, so a weep there drains
into the culture. For both, print at the hot end of the filament's range, with four or more walls,
0.15 mm layers and a touch of extra flow (about 105 %). Leak paths run through the walls, not the
infill, so walls are what to spend on. Water-test the flow insert before it goes on the reactor.

**Print the open well's lid the other way: sparse.** It is insulation over the ice, so low infill in a
pattern that boxes the air into cells, honeycomb or cubic rather than one that leaves it free to
move. Keep its Ø1.5 vent open; ice melting and water warming push air out through it, and a sealed
lid would pressurise the well.

**The coil is wound on the former, and the former stays in.** A coil whose bottom end runs back up
its own middle cannot come off a one-piece mandrel: to unscrew, the mandrel's ridge has to sweep
through the leg. So there is no mandrel. The former is the arbor — chuck the stub below the coil,
wind, and it stays in the reactor holding the turns at pitch, in the dead space it already blocks.
`part = "puck_bottom"` and `part = "puck_top"` are the only tools, one for each end's radius.

1. Bend the bottom end while the tube is still straight and a bender has room, on `puck_bottom`: a
   quarter turn inward, then a quarter turn up, leaving a leg the height of the coil.
2. Lay that end into the former's channel **from the side** — the bends into the foot, the leg up
   the groove. Nothing is threaded into a hole, which is the step that cannot be done later. A tie
   through the stub holds the tail while the first turn goes on.
3. Wind up the former, pushing each turn down onto the ridge below it. The ridge's flat top is what
   sets the pitch; the slack above each turn is there because a part printed standing cannot hold an
   overhang past 45°, and it is why the winding direction matters.
4. Bend the top end on `puck_top`, in open air above the coil: inward a quarter turn, then up.
5. Lower the panel onto the two ends — they are already vertical and parallel — and onto the
   former's spigot. An M3 x 14 cap head goes in radially through the counterbore in the coupling's
   face, crosses the socket and bites the spigot.

The two ends bend at different radii on purpose. The bottom one has to finish inside the coil, so
9.5 mm is as gentle as it can be; the top one only has to reach a seal, so it bends at 11.25 mm and
lands further out, which is as far as the coupling's core lets a seal sit.

A length that has been bent back and forth work-hardens and cracks at the next bend; start from a
fresh piece rather than straightening one.

**The coil condenser's aluminium tube never goes through the vessel's bleach step.** It takes the
7.5 % peroxide with everything else; bleach and chlorite attack it.

---

## Commissioning

**Set the gas rate before anything else.** 0.1–0.5 vvm on 8.17 L is **0.817–4.09 L/min**, which is
16 % to 82 % of the registered 0–5 L/min meter — both ends on scale, which is what that range buys.
The pump is seven times oversized, so the entire band sits in the first part of the needle valve's
travel — that is why the valve is a 3° needle and not the 20° one.

**Watch the DO trace on the first run, with the ring.** The DO probe's face sits 20.6 mm above the sparge ring's
centreline and 0.87 mm off its radius, which is directly over a ring of bubbles. A galvanic probe
reads high with a bubble on the membrane and low with nothing moving past, so this is the one
placement that can be wrong in both directions. A characteristically spiky trace means the probe is
in the plume, and the fix is a bench one — the port's lean and the ring's height are both
parameters.

**Know the replace-the-filter signal.** The sterile filter can rise about **51 %** — from 14.1 kPa
to roughly 21.2 — before 0.5 vvm becomes unreachable with the valve wide open. So _valve fully open
and still short of the rate_ is the signal, and it is not a pump problem.

---

## What to record

The model is waiting on four measurements. If you build one of these, these are the numbers worth
sending back:

1. **The sterile filter's ΔP** at the set flow, from a water manometer across it. It is the largest
   term in the gas budget and the only one that is extrapolated.
2. **The jar's rim**, calipered — the land width on top of the glass, the wall, and the mouth. Three
   registered numbers disagree on two vessels and a caliper says which is wrong.
3. **The baffle's lean.** Print the lid's baffle port and one plate segment, seat them, and measure
   the tilt at a known distance below the lid. The model reports a stacked worst case of −0.28 mm
   running clearance and openly says it cannot tell how much of that lean is real.
4. **Whether the joint holds.** Nobody has yet tightened twelve nuts a third of a turn onto a glass
   jar with a printed flange in between. How much it relaxes, and over what time, is the number this
   document most needs.

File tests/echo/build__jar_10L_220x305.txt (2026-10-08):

ECHO: "build: jar_10L_220x305, shaft drive, 86.5% of capacity; designated light grow 13in"
ECHO: "joint: 12 posts at 62.5701 mm on a 239 mm circle"
ECHO: "joint load: 4212.27 N of gasket seating over 12 posts = 351.023 N each, on M8 bolts and M8 rods"
ECHO: "joint tightening: 114.3 deg past snug on each of the 12 nuts (0.396875 mm of gasket travel on a 1.25 mm pitch); the printed flange creeps, so go back to them"
ECHO: "reactor envelope: 257.6 mm dia x 581.25 mm tall"
ECHO: "printers: the widest printed part is a 257.6 mm disc (lid, base, top base); registered printers that take it: ["prusa_core_one_l", "bambu_h2d", "sovol_sv08", "voron_350", "prusa_xl"]"
ECHO: "base wall thickness: ", 3.7, " cm"
ECHO: "threaded rod length: ", 322, " mm"
ECHO: "base floor: jar lands at r", 97.5, "mm, ring spans r", 82.5, "to r", 110.3, "mm"
ECHO: "light pockets: end at z 331; stopping 6.35 mm under the top base"
ECHO: "lights: 8 tubes - 4 in each of 2 quadrants - on a light that comes 4 to a cord, so 2 cords and nothing spare"
ECHO: "heat pads: 2 x 20W 150x50 behind the lower rib level in the unlit quadrants, 18.9474 W each at 12 V on 7.6 ohm measured, 37.8947 W in all"
ECHO: "stir drive: none fitted for drive_name = shaft; the base is slotted for a magnetic build's fan80x25 in a 164.6 mm carrier"
ECHO: "DO probe lean: 4.5 deg of a 4.5 deg ceiling"
ECHO: "impeller: 94.5 mm in a 210 mm bore, D/T 0.45 (band 0.3-0.5, axial 0.4-0.5); spacing 1 D (band 1-2)"
ECHO: "impeller clearance: centreline 85.05 mm off the floor = 0.9 D (Oldshue allows 1-2), C/T 0.405; 76.9536 mm under the lower impeller and 51.857 mm (0.548751 D) of culture over the upper"
ECHO: "impeller count: 2 on 2.42861 impeller diameters of liquid (H/T 1.09287), where the spacing band allows 0.214303 < n < 1.42861 - short for a pair, which costs the coverage above: 0.548751 D against the 0.5 D floor"
ECHO: "impeller clearance: 0.9 D is below Oldshue's 1-2 D for fluidfoils; this is a pbt_45_4, where Fořt found efficiency higher at C/D 1.0 than 0.5, and coverage over the upper impeller binds at 0.948751 D (docs/agitation.md)"
ECHO: "impeller pumping: shaft turns counter-clockwise seen from above, so the lower impeller pumps up and the upper down and the pair converges on the 70.3073 mm gap between them"
ECHO: "impeller set screws: 2 x M4x6 316 (92029A142) at [0, 120] deg, 5.8 mm of thread in a 3.3 mm tap hole, through a 8 mm collar above the blades"
ECHO: "impeller bore: 8.4 mm straight over a 7.995-8 mm shaft: 0.4 to 0.405 mm of slack, before print shrinkage"
ECHO: "culture: 8.17035 L standing 229.503 mm deep, 86.5% of the 9.44549 L capacity and 79.1391% of the 290 mm internal height"
ECHO: "culture headspace: 1.27514 L of gas space at 86.5% of capacity, above the usual 0.8 by 6.5 points"
ECHO: "impeller: pbt_45_4 Po 1.49248 and flow number 0.887217 from Medek's correlation at 45 deg, extrapolated on ["T/D", "H/T", "baffle count"]"
ECHO: "drive no-load 420 rpm: Re 62274.7, tip 2.07816 m/s, 3.85106 W into 8.17035 L = 471.346 W/m3 mean, 68.8246 W/kg peak, pair under 0.175119 Nm of 0.4903 Nm rated"
ECHO: "drive rated 320 rpm: Re 47447.4, tip 1.58336 m/s, 1.70327 W into 8.17035 L = 208.469 W/m3 mean, 30.4401 W/kg peak, pair under 0.101656 Nm of 0.4903 Nm rated"
ECHO: "thermocouple: 1245N31 on 1/2 NPT, tip 137.4 mm below the lid at 50% engagement, 68.9033 mm under the surface with 170.6 mm to the floor; 127.4 to 147.4 mm over the engagement range"
ECHO: "probe: do_probe carries DO lab g2, reaching 151.597 mm, tip 83.1001 mm under the surface with 156.403 mm to the floor, leaning 4.5 deg"
ECHO: "probe: ph_probe carries pH lab g2, reaching 197.438 mm, tip 128.941 mm under the surface with 110.562 mm to the floor, leaning 0 deg"
ECHO: "transfer no-load 420 rpm: blend to 95% in 3.49317 s; kLa 0.0135231 1/s coalescing, 0.0427636 1/s not, at 1.96576 mm/s superficial gas"
ECHO: "transfer rated 320 rpm: blend to 95% in 4.58479 s; kLa 0.00975788 1/s coalescing, 0.0241583 1/s not, at 1.96576 mm/s superficial gas"
ECHO: "transfer: kLa is van't Riet's air-water correlation, fitted over 500-10000 W/m3, and this vessel runs 208.469; an order of magnitude, not a number"
ECHO: "transfer: blend time is Ruszkowski's, fitted on 0.01-10 m3 fully baffled, and this is 0.00817035 m3; it reproduces Hall's table at a tenth of that"
ECHO: "drive encoder: 12 ppr x 2 channels through 14:1 = 672 counts per output turn, resolving 0.892857 rpm over 100 ms"
ECHO: "shaft: 8x400_316 (1265K66) 7.995-8 mm in a 8 mm bore: -0.007 to 0.005 mm"
ECHO: "shaft gap: 3 mm between the gearbox's shaft and the impeller shaft, centred in the 25 mm coupler, so each shaft is in it by 11 mm"
ECHO: "motor mount height: 13.2 cm"
ECHO: "motor mount: 4 x M4x4.7 18-8 inserts on a 42.8 mm circle, 8 mm M4 screws, 13.25 mm of lid left under them, 6.02 mm to the bearing pocket"
ECHO: "bearing seal: 22x1.5 EPDM on the 608's 22 mm rim at 0% stretch, in a groove to 24.46 mm, 18% radial squeeze, 6.02 mm from the nearest mount insert"
ECHO: "baffles: 3 x 10.3454 x 274.403 mm (274.403 mm clears the floor), 223.907 mm submerged; 0.432561 of Oldshue's four-at-T/12 reference area"
ECHO: "WARNING baffles: 0.432561 of the reference projected area; depth is spent, 4 plates (the next count that spaces equally on 12 ports) would give 0.576748; see docs/agitation.md"
ECHO: "baffle plate: 1.03315 N each, deflecting 2.44439 mm at the tip (0.353796 mm of it the joints); first mode 19.9502 Hz against 7 Hz shaft and 28 Hz blade passing at 420 rpm (the mode is the solid plate's; the joints soften it)"
ECHO: "baffle print: 2 pieces of 137.202 mm, tallest standing 160.202 mm against a 200 mm slenderness cap; the dovetail leaves 4.2 mm of 10 crossing each joint, 0.074088 of the plate's second moment"
ECHO: "baffle clearance: 4.07731 mm nominal to the impeller, less 2.27722 mm the coupling's 0.2 mm of play allows at the lower impeller = 1.80009 mm running"
ECHO: "WARNING baffle plate: 2.44439 mm of tip deflection is over a tenth of the 10.3454 mm plate, so it bends away from the swirl rather than blocking it; thicken it (the lock bore allows more)"
ECHO: "baffle resonance: the 19.9502 Hz mode is crossed by the shaft at 1197.01 rpm and by blade passing at 299.253 rpm, against a 320-420 rpm band; neither is a speed this drive is asked to hold, the nearest clears the band by 6.48346%"
ECHO: "sparge arm: from the air inlet's riser at r 56.5 in to r 9, 66.9536 mm off the floor, 10 mm under the lower impeller's blades, 5 mm short of the shaft; at 0.5 vvm that is 4.08517 L/min"
ECHO: "sparge arm: 3 holes of 3 mm along 31.9 mm at 3.54444 hole diameters, 3.21074 m/s each; bubbles 5.09817 mm at formation, 981.337 a second; the 4 mm bore carries 5.41813 m/s, open area ratio 1.6875"
ECHO: "WARNING sparge arm: extrapolated on ["open area", "bore velocity"]"
ECHO: "sparge arm socket: 4.2 mm bore, 0.2 mm over the riser, 12 mm deep in a 10.2 mm boss of the tube's own section; one M4x6 316 (92029A142) through its 3 mm wall bites the riser by 3 mm; the end is open through a 3.3 mm pilot in 6 mm of stock and plugged by another"
ECHO: "sparge ring: the ring is what caps the baffles, kept without it so the plates print once, at 10.3454 mm, where they would otherwise be 14.5 mm; room outside a baffle does not grow with the mouth"
ECHO: "sparge holes: capillary 96 Pa to launch a bubble against 17.1815 Pa to push gas through, so the holes will not all flow evenly, which Rewatkar & Joshi find does not matter near the impeller"
ECHO: "reach clearance: do_probe's tip passes the upper impeller with 11.2869 mm of radial room, over the -136.546 to -120.354 mm the two share"
ECHO: "reach clearance: ph_probe's tip passes the upper impeller with 3.25 mm of radial room, over the -136.546 to -120.354 mm the two share"
ECHO: "reach clearance: the thermocouple passes the upper impeller with 7.6625 mm of radial room, over the -136.546 to -120.354 mm the two share"
ECHO: "DO probe feed no-load 420 rpm: the vessel turns over at 189.742 mm/s mean and the probe needs 8.84194 mm/s past its face, 21.4594x; mean, not local"
ECHO: "DO probe feed rated 320 rpm: the vessel turns over at 144.566 mm/s mean and the probe needs 8.84194 mm/s past its face, 16.35x; mean, not local"
ECHO: "port fit: do_probe's collet reaches 70.7842 mm from the axis leaning 4.5 deg, and the mouth is 71.1 mm, 0.315836 mm to spare on the way in"
ECHO: "port fit: ph_probe's collet reaches 65.7 mm from the axis leaning 0 deg, and the mouth is 71.1 mm, 5.4 mm to spare on the way in"
ECHO: "sparge support drilling: a support tube vents through a hole drilled between 37.9375 and 88.4342 mm from its top end (past the lid's inner face, short of the culture); nearer the first is better"
ECHO: "sparge riser: 4 x 3 mm tube; the feed is 251.384 mm and each dosing or vent tube 188.174 mm (the feed socket sits 63.21 mm lower); 14.9375 mm proud of its port, 12 mm inside the socket, 0.4 mm of slack through the port's bore"
ECHO: "sparge riser seal: 4x1.5 EPDM (8785N364) in each of 6 ports, at 0% stretch and 18% squeeze; without it each port is a 2.63894 mm2 hole into the headspace"
ECHO: "dosing: Kamoer NKP-DC-S10B pulls 3 x 5 mm tube over 4 risers of 4 mm, 1 mm of interference over 14.9375 mm of stub"
ECHO: "sparge tube stock: 50415K21, 316 SS welded, hard temper; cut 1 x 251.384 mm and 5 x 188.174 mm = 1192.25 mm from a 2000 mm length, leaving 807.747 mm spare"
ECHO: "sparge back-pressure: 172.55 mm of culture over the arm is 1689.67 Pa, plus 96 Pa of capillary = 1785.67 Pa the gas supply has to beat before anything bubbles"
ECHO: "gas line losses: filter 14093.9 Pa (extrapolated), check valve 1928.01 Pa (1241 to crack) and riser 155.83 Pa at 4.08517 L/min, on top of the vessel's 1785.67 and 209.452 Pa on the way back out (the vent slot and up to 88.4342 mm of tube); the pump beats 18172.8 Pa, and the filter alone is 7.89277x the vessel"
ECHO: "gas supply: ReSun 35W settles at 5.79746 L/min against this line, where 4.08517 L/min is wanted, so a throttle has to drop 7130.28 Pa on top of the line's own (not the 21.2507 L/min a back pressure held at the design point suggests)"
ECHO: "gas exhaust: nothing filters the way out; the headspace vents through a support tube to the room. An outlet filter may cost at most 1.7454 kPa per L/min before 4.08517 L/min stops being reachable, 0.505914 of what the inlet filter costs"
ECHO: "gas exhaust slot: a slot of the tube's own 7.06858 mm2 bore costs 154.633 Pa at 4.08517 L/min, and the tube above it 23.517-54.8192 Pa over the 37.9375-88.4342 mm drilling window, together 2.4985-2.93751% of the 7130.28 Pa the exhaust has to spend; file past 1.04095 mm2 (a 1.15125 mm round hole), which the bore clears 6.7905x over"
ECHO: "gas throttle: a valve of Cv 0.034601 passes 4.08517 L/min at that drop; sold Cv should be 2-4x it so the setting sits mid-travel"
ECHO: "gas metering: 0.1-0.5 vvm on 8.17035 L is 0.817035-4.08517 L/min, so a 0-5 L/min rotameter"
ECHO: "gas supply: ReSun 35W's free flow and dead head cannot be simultaneous, together 83.5714% of its electrical input; they are read as the ends of its curve"
ECHO: "gas against the impeller: axial pumping needs 8x the gas stream's power to hold its flow pattern, which at 420 rpm caps aeration at 1.57299 vvm"
ECHO: "port interfaces: all 12 ports on std, so one face o-ring covers the lid and any port takes any function; the worst adjacent pair measures 1.04655 mm against a 1 mm floor"
ECHO: "port layout: 12 ports on a 113 mm circle, 29.2466 mm chord; the full set fits a mouth from 142.025 mm (142.025 uniform std), the reduced set from 78.0017 mm (87.6038 uniform std); this jar's is 142.2"
ECHO: "eccentricity: the mount leaves 12.4 mm of offset, e/T 0.0590476 against Hall's measured 0.2, worth 23.5472% of the centred blend time on Karcz's up-pumping branch, to an unbaffled vessel (this one carries 3 baffles); extrapolated on ["D/T", "H/T", "scale", "baffle count", "pumping mode", "impeller type"]"
ECHO: "lid gasket: cut 142.2 x 158.2 mm from EPDM 1/16 60A (1.5875 mm), recess 1.19062 mm deep (25% squeeze); 1 per 304.8 x 304.8 mm sheet"
ECHO: "lid lip: crowned on a 3.5 mm arc standing 2 mm proud of the wall, so the gasket covers the lip and the crown sinks 0.396875 mm into it; 8 mm of gasket, 3.23766 mm of contact"
ECHO: "lid gasket load: 3.23766 mm of contact, 4212.27 N to hold 25% squeeze, 2.77566 MPa on the glass"
ECHO: "plug o-ring: AS568-160 at 3.67103% stretch; the groove takes ID 137.903 mm down to 131.336 mm (0-5% stretch)"

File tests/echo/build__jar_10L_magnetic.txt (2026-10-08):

ECHO: "build: jar_10L_220x305, magnetic drive, 86.5% of capacity; designated light grow 13in"
ECHO: "joint: 12 posts at 62.5701 mm on a 239 mm circle"
ECHO: "joint load: 4212.27 N of gasket seating over 12 posts = 351.023 N each, on M8 bolts and M8 rods"
ECHO: "joint tightening: 114.3 deg past snug on each of the 12 nuts (0.396875 mm of gasket travel on a 1.25 mm pitch); the printed flange creeps, so go back to them"
ECHO: "reactor envelope: 257.6 mm dia x 357.75 mm tall"
ECHO: "printers: the widest printed part is a 257.6 mm disc (lid, base, top base); registered printers that take it: ["prusa_core_one_l", "bambu_h2d", "sovol_sv08", "voron_350", "prusa_xl"]"
ECHO: "base wall thickness: ", 3.7, " cm"
ECHO: "threaded rod length: ", 322, " mm"
ECHO: "base floor: jar lands at r", 97.5, "mm, ring spans r", 82.5, "to r", 110.3, "mm"
ECHO: "light pockets: end at z 331; stopping 6.35 mm under the top base"
ECHO: "lights: 8 tubes - 4 in each of 2 quadrants - on a light that comes 4 to a cord, so 2 cords and nothing spare"
ECHO: "heat pads: 2 x 20W 150x50 behind the lower rib level in the unlit quadrants, 18.9474 W each at 12 V on 7.6 ohm measured, 37.8947 W in all"
ECHO: "fan joint: 4 x M4 x 40 mm down through the fan into nuts in 4.2 mm hex pockets at the carrier's bottom face, 7.55 mm of carrier over them; the head stands 2.2 mm on the fan, 3.48992 mm under the glass"
ECHO: "fan joint, head down: an M4 x 40 mm cap screw up from the pocket to a nut on the fan stands 4.25 mm over that nut, 1.76008 mm into it - shorten the screw, or build it the other way up"
ECHO: "stir drive: fan80x25 in a 164.6 mm carrier 36.75 mm tall, its top 0 mm under the landing plane, hung on its ear 8 mm off the bottom face; the fan is turned 55 deg to put a flat on the slot's bearing, and the lead leaves its 8 mm notch there for the 14.65 mm slot at 145 deg"
ECHO: "stir magnets: 2 x MAG5x8 on the 40 mm hub at 28 mm pitch, faces 1.24242 mm under the punt and 6.24242 mm from the floor inside"
ECHO: "stir bar: 38x8 centred on the 30 mm punt plateau, overhanging it by 4 mm each end; sweeps r 19 under the sparge arm, 55.49 mm over it and the baffles at r 51.3273; the sparger is still placed on the shaft drive's impeller"
ECHO: "DO probe lean: 4.5 deg of a 4.5 deg ceiling"
ECHO: "culture: 8.17035 L standing 229.503 mm deep, 86.5% of the 9.44549 L capacity and 79.1391% of the 290 mm internal height"
ECHO: "culture headspace: 1.27514 L of gas space at 86.5% of capacity, above the usual 0.8 by 6.5 points"
ECHO: "thermocouple: 1245N31 on 1/2 NPT, tip 137.4 mm below the lid at 50% engagement, 68.9033 mm under the surface with 170.6 mm to the floor; 127.4 to 147.4 mm over the engagement range"
ECHO: "probe: do_probe carries DO lab g2, reaching 151.597 mm, tip 83.1001 mm under the surface with 156.403 mm to the floor, leaning 4.5 deg"
ECHO: "probe: ph_probe carries pH lab g2, reaching 197.438 mm, tip 128.941 mm under the surface with 110.562 mm to the floor, leaning 0 deg"
ECHO: "bearing seal: 22x1.5 EPDM on the 608's 22 mm rim at 0% stretch, in a groove to 24.46 mm, 18% radial squeeze, 6.02 mm from the nearest mount insert"
ECHO: "bearing blank: a 22 mm boss 6.8 mm into the 22.2 mm pocket, sealed by the same ring; a 8 mm pin fills the 8.2 mm bore to the lid's underside; held by the mount's four 8 mm M4 screws"
ECHO: "baffles: 3 x 10.3454 x 274.403 mm (274.403 mm clears the floor), 223.907 mm submerged; 0.432561 of Oldshue's four-at-T/12 reference area"
ECHO: "WARNING baffles: 0.432561 of the reference projected area; depth is spent, 4 plates (the next count that spaces equally on 12 ports) would give 0.576748; see docs/agitation.md"
ECHO: "baffle print: 2 pieces of 137.202 mm, tallest standing 160.202 mm against a 200 mm slenderness cap; the dovetail leaves 4.2 mm of 10 crossing each joint, 0.074088 of the plate's second moment"
ECHO: "sparge arm: from the air inlet's riser at r 56.5 in to r 9, 66.9536 mm off the floor, 10 mm under the lower impeller's blades; at 0.5 vvm that is 4.08517 L/min"
ECHO: "sparge arm: 3 holes of 3 mm along 31.9 mm at 3.54444 hole diameters, 3.21074 m/s each; bubbles 5.09817 mm at formation, 981.337 a second; the 4 mm bore carries 5.41813 m/s, open area ratio 1.6875"
ECHO: "WARNING sparge arm: extrapolated on ["open area", "bore velocity"]"
ECHO: "sparge arm socket: 4.2 mm bore, 0.2 mm over the riser, 12 mm deep in a 10.2 mm boss of the tube's own section; one M4x6 316 (92029A142) through its 3 mm wall bites the riser by 3 mm; the end is open through a 3.3 mm pilot in 6 mm of stock and plugged by another"
ECHO: "sparge ring: the ring is what caps the baffles, kept without it so the plates print once, at 10.3454 mm, where they would otherwise be 14.5 mm; room outside a baffle does not grow with the mouth"
ECHO: "sparge holes: capillary 96 Pa to launch a bubble against 17.1815 Pa to push gas through, so the holes will not all flow evenly, which Rewatkar & Joshi find does not matter near the impeller"
ECHO: "port fit: do_probe's collet reaches 70.7842 mm from the axis leaning 4.5 deg, and the mouth is 71.1 mm, 0.315836 mm to spare on the way in"
ECHO: "port fit: ph_probe's collet reaches 65.7 mm from the axis leaning 0 deg, and the mouth is 71.1 mm, 5.4 mm to spare on the way in"
ECHO: "sparge support drilling: a support tube vents through a hole drilled between 37.9375 and 88.4342 mm from its top end (past the lid's inner face, short of the culture); nearer the first is better"
ECHO: "sparge riser: 4 x 3 mm tube; the feed is 251.384 mm and each dosing or vent tube 188.174 mm (the feed socket sits 63.21 mm lower); 14.9375 mm proud of its port, 12 mm inside the socket, 0.4 mm of slack through the port's bore"
ECHO: "sparge riser seal: 4x1.5 EPDM (8785N364) in each of 6 ports, at 0% stretch and 18% squeeze; without it each port is a 2.63894 mm2 hole into the headspace"
ECHO: "dosing: Kamoer NKP-DC-S10B pulls 3 x 5 mm tube over 4 risers of 4 mm, 1 mm of interference over 14.9375 mm of stub"
ECHO: "sparge tube stock: 50415K21, 316 SS welded, hard temper; cut 1 x 251.384 mm and 5 x 188.174 mm = 1192.25 mm from a 2000 mm length, leaving 807.747 mm spare"
ECHO: "sparge back-pressure: 172.55 mm of culture over the arm is 1689.67 Pa, plus 96 Pa of capillary = 1785.67 Pa the gas supply has to beat before anything bubbles"
ECHO: "gas line losses: filter 14093.9 Pa (extrapolated), check valve 1928.01 Pa (1241 to crack) and riser 155.83 Pa at 4.08517 L/min, on top of the vessel's 1785.67 and 209.452 Pa on the way back out (the vent slot and up to 88.4342 mm of tube); the pump beats 18172.8 Pa, and the filter alone is 7.89277x the vessel"
ECHO: "gas supply: ReSun 35W settles at 5.79746 L/min against this line, where 4.08517 L/min is wanted, so a throttle has to drop 7130.28 Pa on top of the line's own (not the 21.2507 L/min a back pressure held at the design point suggests)"
ECHO: "gas exhaust: nothing filters the way out; the headspace vents through a support tube to the room. An outlet filter may cost at most 1.7454 kPa per L/min before 4.08517 L/min stops being reachable, 0.505914 of what the inlet filter costs"
ECHO: "gas exhaust slot: a slot of the tube's own 7.06858 mm2 bore costs 154.633 Pa at 4.08517 L/min, and the tube above it 23.517-54.8192 Pa over the 37.9375-88.4342 mm drilling window, together 2.4985-2.93751% of the 7130.28 Pa the exhaust has to spend; file past 1.04095 mm2 (a 1.15125 mm round hole), which the bore clears 6.7905x over"
ECHO: "gas throttle: a valve of Cv 0.034601 passes 4.08517 L/min at that drop; sold Cv should be 2-4x it so the setting sits mid-travel"
ECHO: "gas metering: 0.1-0.5 vvm on 8.17035 L is 0.817035-4.08517 L/min, so a 0-5 L/min rotameter"
ECHO: "gas supply: ReSun 35W's free flow and dead head cannot be simultaneous, together 83.5714% of its electrical input; they are read as the ends of its curve"
ECHO: "port interfaces: all 12 ports on std, so one face o-ring covers the lid and any port takes any function; the worst adjacent pair measures 1.04655 mm against a 1 mm floor"
ECHO: "port layout: 12 ports on a 113 mm circle, 29.2466 mm chord; the full set fits a mouth from 142.025 mm (142.025 uniform std), the reduced set from 78.0017 mm (87.6038 uniform std); this jar's is 142.2"
ECHO: "lid gasket: cut 142.2 x 158.2 mm from EPDM 1/16 60A (1.5875 mm), recess 1.19062 mm deep (25% squeeze); 1 per 304.8 x 304.8 mm sheet"
ECHO: "lid lip: crowned on a 3.5 mm arc standing 2 mm proud of the wall, so the gasket covers the lip and the crown sinks 0.396875 mm into it; 8 mm of gasket, 3.23766 mm of contact"
ECHO: "lid gasket load: 3.23766 mm of contact, 4212.27 N to hold 25% squeeze, 2.77566 MPa on the glass"
ECHO: "plug o-ring: AS568-160 at 3.67103% stretch; the groove takes ID 137.903 mm down to 131.336 mm (0-5% stretch)"

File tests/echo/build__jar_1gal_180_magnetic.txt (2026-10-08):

ECHO: "build: jar_1gal_180x197, magnetic drive, 86.5% of capacity; everything else auto"
ECHO: "joint: 12 posts at 52.0981 mm on a 199 mm circle"
ECHO: "joint load: 4786.15 N of gasket seating over 12 posts = 398.846 N each, on M8 bolts and M8 rods"
ECHO: "joint tightening: 114.3 deg past snug on each of the 12 nuts (0.396875 mm of gasket travel on a 1.25 mm pitch); the printed flange creeps, so go back to them"
ECHO: "reactor envelope: 217.6 mm dia x 244.75 mm tall"
ECHO: "printers: the widest printed part is a 217.6 mm disc (lid, base, top base); registered printers that take it: ["prusa_core_one", "voron_250", "bambu_x1c", "prusa_core_one_l", "bambu_h2d", "sovol_sv08", "voron_350", "prusa_xl"]"
ECHO: "base wall thickness: ", 3.7, " cm"
ECHO: "threaded rod length: ", 214, " mm"
ECHO: "base floor: jar lands at r", 77.5, "mm, ring spans r", 62.5, "to r", 90.3, "mm"
ECHO: "light pockets: end at z 218; stopping 6.35 mm under the top base"
ECHO: "lights: 6 tubes - 3 in each of 2 quadrants - on a light that comes 4 to a cord, so 2 cords and 2 tubes left over"
ECHO: "fan joint: 4 x M4 x 35 mm down through the fan into nuts in 4.2 mm hex pockets at the carrier's bottom face, 2.55 mm of carrier over them; the head stands 2.2 mm on the fan, 4.65793 mm under the glass"
ECHO: "fan joint, head down: an M4 x 35 mm cap screw up from the pocket to a nut on the fan stands 4.25 mm over that nut, 0.592071 mm into it - shorten the screw, or build it the other way up"
ECHO: "stir drive: fan80x25 in a 124.6 mm carrier 31.75 mm tall, its top 0 mm under the landing plane, hung on its ear 8 mm off the bottom face; the fan is turned 45 deg to put a flat on the slot's bearing, and the lead leaves its 8 mm notch there for the 14.55 mm slot at 135 deg"
ECHO: "stir magnets: 2 x MAG5x8 on the 40 mm hub at 28 mm pitch, faces 1 mm under the punt and 6 mm from the floor inside"
ECHO: "stir bar: 38x8 centred on the 100 mm punt plateau, wholly on it; sweeps r 19 under the sparge arm, 40.5628 mm over it and the baffles at r 54.2273; the sparger is still placed on the shaft drive's impeller"
ECHO: "DO probe lean: 4.5 deg of a 4.5 deg ceiling"
ECHO: "culture: 3.54267 L standing 153.357 mm deep, 86.5% of the 4.09557 L capacity and 82.8957% of the 185 mm internal height"
ECHO: "culture headspace: 0.552902 L of gas space at 86.5% of capacity, above the usual 0.8 by 6.5 points"
ECHO: "thermocouple: 1245N31 on 1/2 NPT, tip 137.4 mm below the lid at 50% engagement, 97.7571 mm under the surface with 62.6 mm to the floor; 127.4 to 147.4 mm over the engagement range"
ECHO: "probe: do_probe carries DO lab g2, reaching 151.597 mm, tip 111.954 mm under the surface with 48.4033 mm to the floor, leaning 4.5 deg"
ECHO: "probe: ph_probe carries pH lab g2, reaching 197.438 mm, tip 157.795 mm under the surface with 2.5624 mm to the floor, leaning 0 deg"
ECHO: "bearing seal: 22x1.5 EPDM on the 608's 22 mm rim at 0% stretch, in a groove to 24.46 mm, 18% radial squeeze, 6.02 mm from the nearest mount insert"
ECHO: "bearing blank: a 22 mm boss 6.8 mm into the 22.2 mm pocket, sealed by the same ring; a 8 mm pin fills the 8.2 mm bore to the lid's underside; held by the mount's four 8 mm M4 screws"
ECHO: "baffles: 3 x 10.3454 x 166.076 mm (166.076 mm clears the floor), 144.433 mm submerged; 0.515826 of Oldshue's four-at-T/12 reference area"
ECHO: "WARNING baffles: 0.515826 of the reference projected area; depth is spent, 4 plates (the next count that spaces equally on 12 ports) would give 0.687768; see docs/agitation.md"
ECHO: "baffle print: 1 piece of 166.076 mm, tallest standing 189.076 mm against a 200 mm slenderness cap"
ECHO: "sparge arm: from the air inlet's riser at r 59.4 in to r 9, 52.0264 mm off the floor, 10 mm under the lower impeller's blades; at 0.5 vvm that is 1.77134 L/min"
ECHO: "sparge arm: 3 holes of 3 mm along 34.8 mm at 3.86667 hole diameters, 1.39218 m/s each; bubbles 5.09817 mm at formation, 425.509 a second; the 4 mm bore carries 2.34931 m/s, open area ratio 1.6875"
ECHO: "WARNING sparge arm: extrapolated on ["open area", "bore velocity"]"
ECHO: "sparge arm socket: 4.2 mm bore, 0.2 mm over the riser, 12 mm deep in a 10.2 mm boss of the tube's own section; one M4x6 316 (92029A142) through its 3 mm wall bites the riser by 3 mm; the end is open through a 3.3 mm pilot in 6 mm of stock and plugged by another"
ECHO: "sparge ring: the ring is what caps the baffles, kept without it so the plates print once, at 10.3454 mm, where they would otherwise be 17.0892 mm; room outside a baffle does not grow with the mouth"
ECHO: "sparge holes: capillary 96 Pa to launch a bubble against 3.23028 Pa to push gas through, so the holes will not all flow evenly, which Rewatkar & Joshi find does not matter near the impeller"
ECHO: "reach clearance: ph_probe's tip passes the stir bar with 34.4 mm of radial room, over the -193 to -185 mm the two share"
ECHO: "port fit: do_probe's collet reaches 73.6842 mm from the axis leaning 4.5 deg, and the mouth is 74 mm, 0.315836 mm to spare on the way in"
ECHO: "port fit: ph_probe's collet reaches 68.6 mm from the axis leaning 0 deg, and the mouth is 74 mm, 5.4 mm to spare on the way in"
ECHO: "sparge support drilling: a support tube vents through a hole drilled between 37.9375 and 59.5804 mm from its top end (past the lid's inner face, short of the culture); nearer the first is better"
ECHO: "sparge riser: 4 x 3 mm tube; the feed is 158.311 mm and each dosing or vent tube 105.374 mm (the feed socket sits 52.9372 mm lower); 14.9375 mm proud of its port, 12 mm inside the socket, 0.4 mm of slack through the port's bore"
ECHO: "sparge riser seal: 4x1.5 EPDM (8785N364) in each of 6 ports, at 0% stretch and 18% squeeze; without it each port is a 2.63894 mm2 hole into the headspace"
ECHO: "dosing: Kamoer NKP-DC-S10B pulls 3 x 5 mm tube over 4 risers of 4 mm, 1 mm of interference over 14.9375 mm of stub"
ECHO: "sparge tube stock: 50415K21, 316 SS welded, hard temper; cut 1 x 158.311 mm and 5 x 105.374 mm = 685.18 mm from a 1000 mm length, leaving 314.82 mm spare"
ECHO: "sparge back-pressure: 108.331 mm of culture over the arm is 1060.81 Pa, plus 96 Pa of capillary = 1156.81 Pa the gas supply has to beat before anything bubbles"
ECHO: "gas line losses: filter 6111.11 Pa (extrapolated), check valve 1370.96 Pa (1241 to crack) and riser 42.5515 Pa at 1.77134 L/min, on top of the vessel's 1156.81 and 45.0868 Pa on the way back out (the vent slot and up to 59.5804 mm of tube); the pump beats 8726.51 Pa, and the filter alone is 5.28272x the vessel"
ECHO: "gas supply: ReSun 35W settles at 6.14899 L/min against this line, where 1.77134 L/min is wanted, so a throttle has to drop 17537.7 Pa on top of the line's own (not the 43.9917 L/min a back pressure held at the design point suggests)"
ECHO: "gas exhaust: nothing filters the way out; the headspace vents through a support tube to the room. An outlet filter may cost at most 9.90084 kPa per L/min before 1.77134 L/min stops being reachable, 2.86981 of what the inlet filter costs"
ECHO: "gas exhaust slot: a slot of the tube's own 7.06858 mm2 bore costs 29.0725 Pa at 1.77134 L/min, and the tube above it 10.197-16.0143 Pa over the 37.9375-59.5804 mm drilling window, together 0.223915-0.257085% of the 17537.7 Pa the exhaust has to spend; file past 0.287798 mm2 (a 0.605339 mm round hole), which the bore clears 24.5609x over"
ECHO: "gas throttle: a valve of Cv 0.00996833 passes 1.77134 L/min at that drop; sold Cv should be 2-4x it so the setting sits mid-travel"
ECHO: "gas metering: 0.1-0.5 vvm on 3.54267 L is 0.354267-1.77134 L/min, so a 0-2 L/min rotameter"
ECHO: "gas supply: ReSun 35W's free flow and dead head cannot be simultaneous, together 83.5714% of its electrical input; they are read as the ends of its curve"
ECHO: "port interfaces: all 12 ports on std, so one face o-ring covers the lid and any port takes any function; the worst adjacent pair measures 2.5477 mm against a 1 mm floor"
ECHO: "port layout: 12 ports on a 118.8 mm circle, 30.7477 mm chord; the full set fits a mouth from 142.025 mm (142.025 uniform std), the reduced set from 78.0017 mm (87.6038 uniform std); this jar's is 148"
ECHO: "lid gasket: cut 148 x 165 mm from EPDM 1/16 60A (1.5875 mm), recess 1.19062 mm deep (25% squeeze); 1 per 304.8 x 304.8 mm sheet"
ECHO: "lid lip: crowned on a 3.75 mm arc standing 2.5 mm proud of the wall, so the gasket covers the lip and the crown sinks 0.396875 mm into it; 8.5 mm of gasket, 3.35801 mm of contact"
ECHO: "lid gasket load: 3.35801 mm of contact, 4786.15 N to hold 25% squeeze, 2.91759 MPa on the glass"
ECHO: "plug o-ring: AS568-161 at 3.10913% stretch; the groove takes ID 143.703 mm down to 136.86 mm (0-5% stretch)"

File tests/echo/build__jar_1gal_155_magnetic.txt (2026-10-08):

ECHO: "build: jar_1gal_155x251, magnetic drive, 86.5% of capacity; designated lid centre plain"
ECHO: "joint: 12 posts at 45.6316 mm on a 174.3 mm circle"
ECHO: "joint load: 1034.92 N of gasket seating over 12 posts = 86.2437 N each, on M8 bolts and M8 rods"
ECHO: "joint tightening: 114.3 deg past snug on each of the 12 nuts (0.396875 mm of gasket travel on a 1.25 mm pitch); the printed flange creeps, so go back to them"
ECHO: "reactor envelope: 192.9 mm dia x 299 mm tall"
ECHO: "printers: the widest printed part is a 192.9 mm disc (lid, base, top base); registered printers that take it: ["prusa_mk3s", "prusa_core_one", "voron_250", "bambu_x1c", "prusa_core_one_l", "bambu_h2d", "sovol_sv08", "voron_350", "prusa_xl"]"
ECHO: "base wall thickness: ", 3.7, " cm"
ECHO: "threaded rod length: ", 268, " mm"
ECHO: "base floor: jar lands at r", 63.65, "mm, ring spans r", 48.65, "to r", 77.95, "mm"
ECHO: "light pockets: end at z 218; stopping 24.6 mm under the top base"
ECHO: "lights: 6 tubes - 3 in each of 2 quadrants - on a light that comes 4 to a cord, so 2 cords and 2 tubes left over"
ECHO: "fan joint: 4 x M4 x 30 mm down through the fan into nuts in 4.2 mm hex pockets at the carrier's bottom face, 1.8 mm of carrier over them; the head stands 2.2 mm on the fan, 4.8 mm under the glass"
ECHO: "fan joint, head down: an M4 x 30 mm cap screw up from the pocket to a nut on the fan stands 0 mm over that nut, 3.8 mm under the glass"
ECHO: "stir drive: fan60x25 in a 96.9 mm carrier 31 mm tall, its top 1 mm under the landing plane, hung on its ear 8 mm off the bottom face; the fan is turned 45 deg to put a flat on the slot's bearing, and the lead leaves its 8 mm notch there for the 14.55 mm slot at 135 deg"
ECHO: "stir riser: 36 mm under the base, which keeps the light's 4 mm floor; walls at r [50.15, 63.65, 82.25, 94.95], keyed into every light's cord notch"
ECHO: "stir magnets: 2 x MAG5x8 on the 31.5 mm hub at 19.5 mm pitch, faces 1 mm under the punt and 4 mm from the floor inside"
ECHO: "stir bar: 38x8 centred on the 73 mm punt plateau, wholly on it; sweeps r 19 under the sparge arm, 32.8379 mm over it; the sparger is still placed on the shaft drive's impeller"
ECHO: "DO probe lean: 4.5 deg of a 4.5 deg ceiling"
ECHO: "culture: 3.34624 L standing 188.59 mm deep, 86.5% of the 3.86848 L capacity and 77.9297% of the 242 mm internal height"
ECHO: "culture headspace: 0.522245 L of gas space at 86.5% of capacity, above the usual 0.8 by 6.5 points"
ECHO: "thermocouple: 3872K129 on 1/8 NPT, tip 134.9 mm below the lid at 50% engagement, 73.4898 mm under the surface with 121.1 mm to the floor; 127.4 to 142.4 mm over the engagement range"
ECHO: "probe: do_probe carries DO lab g2, reaching 151.597 mm, tip 90.1865 mm under the surface with 104.403 mm to the floor, leaning 4.5 deg"
ECHO: "probe: ph_probe carries pH lab g2, reaching 197.438 mm, tip 136.027 mm under the surface with 58.5624 mm to the floor, leaning 0 deg"
ECHO: "baffles: none on this lid, so the vessel is unbaffled and will swirl rather than mix"
ECHO: "sparge arm: from the air inlet's riser at r 33.3 in to r 9, 44.3016 mm off the floor, 10 mm under the lower impeller's blades; at 0.5 vvm that is 1.67312 L/min"
ECHO: "sparge arm: 1 holes of 3 mm along 8.7 mm at 2.9 hole diameters, 3.94496 m/s each; bubbles 5.09817 mm at formation, 401.915 a second; the 4 mm bore carries 2.21904 m/s, open area ratio 0.5625"
ECHO: "WARNING sparge arm: extrapolated on ["hole pitch"]"
ECHO: "sparge arm socket: 4.2 mm bore, 0.2 mm over the riser, 12 mm deep in a 10.2 mm boss of the tube's own section; one M4x6 316 (92029A142) through its 3 mm wall bites the riser by 3 mm; the end is open through a 3.3 mm pilot in 6 mm of stock and plugged by another"
ECHO: "sparge holes: capillary 96 Pa to launch a bubble against 25.9379 Pa to push gas through, so the holes will not all flow evenly, which Rewatkar & Joshi find does not matter near the impeller"
ECHO: "port fit: do_probe's collet reaches 47.5842 mm from the axis leaning 4.5 deg, and the mouth is 47.9 mm, 0.315836 mm to spare on the way in"
ECHO: "port fit: ph_probe's collet reaches 42.5 mm from the axis leaning 0 deg, and the mouth is 47.9 mm, 5.4 mm to spare on the way in"
ECHO: "sparge support drilling: a support tube vents through a hole drilled between 37.9375 and 81.3477 mm from its top end (past the lid's inner face, short of the culture); nearer the first is better"
ECHO: "sparge riser: 4 x 3 mm tube; the feed is 222.036 mm and each dosing or vent tube 174.415 mm (the feed socket sits 47.6211 mm lower); 14.9375 mm proud of its port, 12 mm inside the socket, 0.4 mm of slack through the port's bore"
ECHO: "sparge riser seal: 4x1.5 EPDM (8785N364) in each of 3 ports, at 0% stretch and 18% squeeze; without it each port is a 2.63894 mm2 hole into the headspace"
ECHO: "dosing: Kamoer NKP-DC-S10B pulls 3 x 5 mm tube over 1 riser of 4 mm, 1 mm of interference over 14.9375 mm of stub"
ECHO: "sparge tube stock: 50415K21, 316 SS welded, hard temper; cut 1 x 222.036 mm and 2 x 174.415 mm = 570.866 mm from a 1000 mm length, leaving 429.134 mm spare"
ECHO: "sparge back-pressure: 150.288 mm of culture over the arm is 1471.67 Pa, plus 96 Pa of capillary = 1567.67 Pa the gas supply has to beat before anything bubbles"
ECHO: "gas line losses: filter 5772.26 Pa (extrapolated), check valve 1356.48 Pa (1241 to crack) and riser 56.3705 Pa at 1.67312 L/min, on top of the vessel's 1567.67 and 46.5905 Pa on the way back out (the vent slot and up to 81.3477 mm of tube); the pump beats 8799.37 Pa, and the filter alone is 3.68205x the vessel"
ECHO: "gas supply: ReSun 35W settles at 6.03551 L/min against this line, where 1.67312 L/min is wanted, so a throttle has to drop 17505.6 Pa on top of the line's own (not the 43.8163 L/min a back pressure held at the design point suggests)"
ECHO: "gas exhaust: nothing filters the way out; the headspace vents through a support tube to the room. An outlet filter may cost at most 10.4629 kPa per L/min before 1.67312 L/min stops being reachable, 3.03272 of what the inlet filter costs"
ECHO: "gas exhaust slot: a slot of the tube's own 7.06858 mm2 bore costs 25.9379 Pa at 1.67312 L/min, and the tube above it 9.63158-20.6526 Pa over the 37.9375-81.3477 mm drilling window, together 0.203189-0.266145% of the 17505.6 Pa the exhaust has to spend; file past 0.272089 mm2 (a 0.588587 mm round hole), which the bore clears 25.979x over"
ECHO: "gas throttle: a valve of Cv 0.00942111 passes 1.67312 L/min at that drop; sold Cv should be 2-4x it so the setting sits mid-travel"
ECHO: "gas metering: 0.1-0.5 vvm on 3.34624 L is 0.334624-1.67312 L/min, so a 0-2 L/min rotameter"
ECHO: "gas supply: ReSun 35W's free flow and dead head cannot be simultaneous, together 83.5714% of its electrical input; they are read as the ends of its curve"
ECHO: "port interfaces: all 6 ports on std, so one face o-ring covers the lid and any port takes any function; the worst adjacent pair measures 5.1 mm against a 1 mm floor"
ECHO: "port layout: 6 ports on a 66.6 mm circle, 33.3 mm chord; the full set fits a mouth from 142.025 mm (142.025 uniform std), the reduced set from 78.0017 mm (87.6038 uniform std); this jar's is 95.8"
ECHO: "lid gasket: cut 95.8 x 103.8 mm from EPDM 1/16 60A (1.5875 mm), recess 1.19062 mm deep (25% squeeze); 4 per 304.8 x 304.8 mm sheet"
ECHO: "lid lip: crowned on a 1.5 mm arc standing 0 mm proud of the wall, so the gasket covers the lip and the crown sinks 0.396875 mm into it; 4 mm of gasket, 2.03285 mm of contact"
ECHO: "lid gasket load: 2.03285 mm of contact, 1034.92 N to hold 25% squeeze, 1.6402 MPa on the glass"
ECHO: "plug o-ring: AS568-153 at 3.31173% stretch; the groove takes ID 91.5032 mm down to 87.1459 mm (0-5% stretch)"

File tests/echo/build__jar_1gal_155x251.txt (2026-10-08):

ECHO: "build: jar_1gal_155x251, airlift drive, 86.5% of capacity; everything else auto"
ECHO: "joint: 12 posts at 45.6316 mm on a 174.3 mm circle"
ECHO: "joint load: 1034.92 N of gasket seating over 12 posts = 86.2437 N each, on M8 bolts and M8 rods"
ECHO: "joint tightening: 114.3 deg past snug on each of the 12 nuts (0.396875 mm of gasket travel on a 1.25 mm pitch); the printed flange creeps, so go back to them"
ECHO: "reactor envelope: 192.9 mm dia x 263 mm tall"
ECHO: "printers: the widest printed part is a 192.9 mm disc (lid, base, top base); registered printers that take it: ["prusa_mk3s", "prusa_core_one", "voron_250", "bambu_x1c", "prusa_core_one_l", "bambu_h2d", "sovol_sv08", "voron_350", "prusa_xl"]"
ECHO: "base wall thickness: ", 3.7, " cm"
ECHO: "threaded rod length: ", 268, " mm"
ECHO: "base floor: jar lands at r", 63.65, "mm, ring spans r", 48.65, "to r", 77.95, "mm"
ECHO: "light pockets: end at z 218; stopping 24.6 mm under the top base"
ECHO: "lights: 6 tubes - 3 in each of 2 quadrants - on a light that comes 4 to a cord, so 2 cords and 2 tubes left over"
ECHO: "stir drive: the base is not slotted; a magnetic build of this jar stands on a 36 mm riser for its fan"
ECHO: "draft tube: 89 mm bore, 93 mm outside, 113.72 mm long from 42.5508 to 156.271 mm off the floor, on 3 feet of 38.3188 mm; 1.4 mm each side through the mouth, and the ring inside it keeps 1.25 mm to its wall, so it shifts up to 2.5 mm"
ECHO: "draft tube areas: riser 6221.14 mm2 inside, downcomer 10714 mm2 outside, Ad/Ar 1.72219; the 38.3188 mm gaps under and over it give the turning flow the downcomer's own area, K_B 11.402"
ECHO: "draft tube gas: 4.48235 mm/s superficial in the riser at 0.5 vvm"
ECHO: "DO probe lean: none, hanging straight inside the draft tube"
ECHO: "culture: 3.34624 L standing 188.59 mm deep, 86.5% of the 3.86848 L capacity and 77.9297% of the 242 mm internal height"
ECHO: "culture headspace: 0.522245 L of gas space at 86.5% of capacity, above the usual 0.8 by 6.5 points"
ECHO: "thermocouple: 3872K129 on 1/8 NPT, tip 134.9 mm below the lid at 50% engagement, 73.4898 mm under the surface with 121.1 mm to the floor; 127.4 to 142.4 mm over the engagement range"
ECHO: "probe: do_probe carries DO lab g2, reaching 151.538 mm, tip 90.1274 mm under the surface with 104.462 mm to the floor, leaning 0 deg"
ECHO: "probe: ph_probe carries pH lab g2, reaching 197.438 mm, tip 136.027 mm under the surface with 58.5624 mm to the floor, leaning 0 deg"
ECHO: "baffles: none on this lid, so the vessel is unbaffled and will swirl rather than mix"
ECHO: "sparge ring: 79.5727 mm, 19.4637 mm off the floor, its underside 10 mm over the highest glass under it, which stands 6 mm off the floor"
ECHO: "sparge ring fits: 1.25 mm to the draft tube, 4.65 mm to the jar's mouth on the way in; a 6.4 mm tube reaching 6.92731 across its corners, on a 4 mm bore of 12.5664 mm2"
ECHO: "sparger: 1 ring(s) at [39.7863] mm carrying [8] holes of 3 mm, 8 in all at 0.49312 m/s"
ECHO: "sparger bubbles: 5.09817 mm at formation, 401.915 a second"
ECHO: "sparger feed run: 4 mm bore carrying 2.21904 m/s, 2.96433 Pa of velocity head against 0.405279 Pa at a hole, open area ratio 4.5"
ECHO: "sparger rings: [1.10952] m/s at 2 path(s) each, open area ratio [2.25], [0.741084] Pa of velocity head - open area 4.5 is above 1, so the holes compete with their supply"
ECHO: "sparger envelope: r [36.3227, 43.25] mm, to clear the baffles and pass the mouth"
ECHO: "sparger pitch: [10.416] hole diameters between holes (floor 3, reasoned, not cited)"
ECHO: "WARNING sparger: extrapolated on ["open area", "bore velocity"]"
ECHO: "sparge holes: 8 x 3 mm at 31.2481 mm spacing; at 0.5 vvm that is 1.67312 L/min through them at 0.49312 m/s"
ECHO: "sparge holes: capillary 96 Pa to launch a bubble against 0.405279 Pa to push gas through, so the holes will not all flow evenly, which Rewatkar & Joshi find does not matter near the impeller"
ECHO: "reach clearance: do_probe's tip passes the draft tube with 2.7 mm of radial room, over the -213.449 to -99.729 mm the two share"
ECHO: "reach clearance: ph_probe's tip passes the draft tube with 2.7 mm of radial room, over the -213.449 to -99.729 mm the two share"
ECHO: "reach clearance: the thermocouple passes the draft tube with 7.1125 mm of radial room, over the -213.449 to -99.729 mm the two share"
ECHO: "port fit: do_probe's collet reaches 42.5 mm from the axis leaning 0 deg, and the mouth is 47.9 mm, 5.4 mm to spare on the way in"
ECHO: "port fit: ph_probe's collet reaches 42.5 mm from the axis leaning 0 deg, and the mouth is 47.9 mm, 5.4 mm to spare on the way in"
ECHO: "sparge support drilling: a support tube vents through a hole drilled between 37.9375 and 81.3477 mm from its top end (past the lid's inner face, short of the culture); nearer the first is better"
ECHO: "sparge support: 3 tubes at [180, 60, 300] deg; 203.073 mm of free support tube and 196.936 mm of feed, so a support is 0.593925 N/mm, 1.68371 mm of sway per newton against 1.25 mm to the draft tube"
ECHO: "sparge riser: 4 x 3 mm tube; the feed is 246.874 mm and each support 253.01 mm (the feed socket sits 6.13634 mm higher); 14.9375 mm proud of its port, 12 mm inside the socket, 0.4 mm of slack through the port's bore"
ECHO: "sparge riser seal: 4x1.5 EPDM (8785N364) in each of 3 ports, at 0% stretch and 18% squeeze; without it each port is a 2.63894 mm2 hole into the headspace"
ECHO: "dosing: Kamoer NKP-DC-S10B pulls 3 x 5 mm tube over 1 riser of 4 mm, 1 mm of interference over 14.9375 mm of stub"
ECHO: "sparge tube stock: 50415K21, 316 SS welded, hard temper; cut 1 x 246.874 mm and 2 x 253.01 mm = 752.894 mm from a 1000 mm length, leaving 247.106 mm spare"
ECHO: "sparge back-pressure: 175.126 mm of culture over the ring is 1714.9 Pa, plus 96 Pa of capillary = 1810.9 Pa the gas supply has to beat before anything bubbles"
ECHO: "gas line losses: filter 5772.26 Pa (extrapolated), check valve 1356.21 Pa (1241 to crack) and riser 62.6764 Pa at 1.67312 L/min, on top of the vessel's 1810.9 and 46.5905 Pa on the way back out (the vent slot and up to 81.3477 mm of tube); the pump beats 9048.63 Pa, and the filter alone is 3.18752x the vessel"
ECHO: "gas supply: ReSun 35W settles at 5.96957 L/min against this line, where 1.67312 L/min is wanted, so a throttle has to drop 17256.4 Pa on top of the line's own (not the 43.2163 L/min a back pressure held at the design point suggests)"
ECHO: "gas exhaust: nothing filters the way out; the headspace vents through a support tube to the room. An outlet filter may cost at most 10.3139 kPa per L/min before 1.67312 L/min stops being reachable, 2.98954 of what the inlet filter costs"
ECHO: "gas exhaust slot: a slot of the tube's own 7.06858 mm2 bore costs 25.9379 Pa at 1.67312 L/min, and the tube above it 9.63158-20.6526 Pa over the 37.9375-81.3477 mm drilling window, together 0.206123-0.26999% of the 17256.4 Pa the exhaust has to spend; file past 0.274047 mm2 (a 0.590701 mm round hole), which the bore clears 25.7933x over"
ECHO: "gas throttle: a valve of Cv 0.00947819 passes 1.67312 L/min at that drop; sold Cv should be 2-4x it so the setting sits mid-travel"
ECHO: "gas metering: 0.1-0.5 vvm on 3.34624 L is 0.334624-1.67312 L/min, so a 0-2 L/min rotameter"
ECHO: "gas supply: ReSun 35W's free flow and dead head cannot be simultaneous, together 83.5714% of its electrical input; they are read as the ends of its curve"
ECHO: "port interfaces: all 6 ports on std, so one face o-ring covers the lid and any port takes any function; the worst adjacent pair measures 5.1 mm against a 1 mm floor"
ECHO: "port layout: 6 ports on a 66.6 mm circle, 33.3 mm chord; the full set fits a mouth from 142.025 mm (142.025 uniform std), the reduced set from 78.0017 mm (87.6038 uniform std); this jar's is 95.8"
ECHO: "lid gasket: cut 95.8 x 103.8 mm from EPDM 1/16 60A (1.5875 mm), recess 1.19062 mm deep (25% squeeze); 4 per 304.8 x 304.8 mm sheet"
ECHO: "lid lip: crowned on a 1.5 mm arc standing 0 mm proud of the wall, so the gasket covers the lip and the crown sinks 0.396875 mm into it; 4 mm of gasket, 2.03285 mm of contact"
ECHO: "lid gasket load: 2.03285 mm of contact, 1034.92 N to hold 25% squeeze, 1.6402 MPa on the glass"
ECHO: "plug o-ring: AS568-153 at 3.31173% stretch; the groove takes ID 91.5032 mm down to 87.1459 mm (0-5% stretch)"

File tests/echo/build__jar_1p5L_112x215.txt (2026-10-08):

ECHO: "build: jar_1p5L_112x215, airlift drive, 86.5% of capacity; everything else auto"
ECHO: "joint: 8 posts at 51.2472 mm on a 130.5 mm circle"
ECHO: "joint load: 1335.79 N of gasket seating over 8 posts = 166.974 N each, on M8 bolts and M8 rods"
ECHO: "joint tightening: 114.3 deg past snug on each of the 8 nuts (0.396875 mm of gasket travel on a 1.25 mm pitch); the printed flange creeps, so go back to them"
ECHO: "reactor envelope: 149.1 mm dia x 248.515 mm tall"
ECHO: "printers: the widest printed part is a 149.1 mm disc (lid, base, top base); registered printers that take it: ["prusa_mk3s", "prusa_core_one", "voron_250", "bambu_x1c", "prusa_core_one_l", "bambu_h2d", "sovol_sv08", "voron_350", "prusa_xl"]"
ECHO: "base wall thickness: ", 3.7, " cm"
ECHO: "threaded rod length: ", 232, " mm"
ECHO: "base floor: jar lands at r", 48.25, "mm, ring spans r", 33.25, "to r", 56.05, "mm"
ECHO: "light pockets: end at z 218; stopping 10.1153 mm under the top base"
ECHO: "lights: 6 tubes - 3 in each of 2 quadrants - on a light that comes 4 to a cord, so 2 cords and 2 tubes left over"
ECHO: "stir drive: none fitted for drive_name = airlift; the base is slotted for a magnetic build's fan40x11 in a 66.1 mm carrier"
ECHO: "draft tube: 81.6 mm bore, 85.6 mm outside, 153.172 mm long from 11.6501 to 164.823 mm off the floor, on 3 feet of 10.3704 mm; 1.4 mm each side through the mouth, and the ring inside it keeps 1.25 mm to its wall, so it shifts up to 1.25 mm"
ECHO: "draft tube areas: riser 5229.62 mm2 inside, downcomer 2658.49 mm2 outside, Ad/Ar 0.508352; the 10.3704 mm gaps under and over it give the turning flow the downcomer's own area, K_B 11.402"
ECHO: "draft tube gas: 2.31532 mm/s superficial in the riser at 0.5 vvm"
ECHO: "DO probe lean: none, hanging straight inside the draft tube"
ECHO: "culture: 1.45299 L standing 168.193 mm deep, 86.5% of the 1.67975 L capacity and 82.4475% of the 204 mm internal height"
ECHO: "culture headspace: 0.226767 L of gas space at 86.5% of capacity, above the usual 0.8 by 6.5 points"
ECHO: "thermocouple: 3872K129 on 1/8 NPT, tip 134.9 mm below the lid at 50% engagement, 91.0929 mm under the surface with 84.1 mm to the floor; 127.4 to 142.4 mm over the engagement range"
ECHO: "probe: do_probe carries DO lab g2, reaching 151.538 mm, tip 107.73 mm under the surface with 67.4624 mm to the floor, leaning 0 deg"
ECHO: "probe: ph_probe carries pH lab g2, reaching 197.438 mm, tip 153.63 mm under the surface with 21.5624 mm to the floor, leaning 0 deg"
ECHO: "baffles: none on this lid, so the vessel is unbaffled and will swirl rather than mix"
ECHO: "sparge ring: 72.1727 mm, 16.1481 mm off the floor, its underside 10 mm over the highest glass under it, which stands 2.68445 mm off the floor"
ECHO: "sparge ring fits: 1.25 mm to the draft tube, 4.65 mm to the jar's mouth on the way in; a 6.4 mm tube reaching 6.92731 across its corners, on a 4 mm bore of 12.5664 mm2"
ECHO: "sparger: 1 ring(s) at [36.0863] mm carrying [8] holes of 3 mm, 8 in all at 0.21412 m/s"
ECHO: "sparger bubbles: 5.09817 mm at formation, 174.518 a second"
ECHO: "sparger feed run: 4 mm bore carrying 0.963542 m/s, 0.558905 Pa of velocity head against 0.0764126 Pa at a hole, open area ratio 4.5"
ECHO: "sparger rings: [0.481771] m/s at 2 path(s) each, open area ratio [2.25], [0.139726] Pa of velocity head - open area 4.5 is above 1, so the holes compete with their supply"
ECHO: "sparger envelope: r [32.6227, 39.55] mm, to clear the baffles and pass the mouth"
ECHO: "sparger pitch: [9.44738] hole diameters between holes (floor 3, reasoned, not cited)"
ECHO: "WARNING sparger: extrapolated on ["orifice velocity", "open area", "bore velocity"]"
ECHO: "sparge holes: 8 x 3 mm at 28.3421 mm spacing; at 0.5 vvm that is 0.726494 L/min through them at 0.21412 m/s"
ECHO: "sparge holes: capillary 96 Pa to launch a bubble against 0.0764126 Pa to push gas through, so the holes will not all flow evenly, which Rewatkar & Joshi find does not matter near the impeller"
ECHO: "reach clearance: do_probe's collet passes the draft tube with 0.75 mm of radial room, over the -207.35 to -54.1775 mm the two share"
ECHO: "reach clearance: do_probe's tip passes the draft tube with 3.95 mm of radial room, over the -207.35 to -54.1775 mm the two share"
ECHO: "reach clearance: ph_probe's collet passes the draft tube with 0.75 mm of radial room, over the -207.35 to -54.1775 mm the two share"
ECHO: "reach clearance: ph_probe's tip passes the draft tube with 3.95 mm of radial room, over the -207.35 to -54.1775 mm the two share"
ECHO: "reach clearance: the thermocouple passes the draft tube with 8.3625 mm of radial room, over the -207.35 to -54.1775 mm the two share"
ECHO: "port fit: do_probe's collet reaches 38.8 mm from the axis leaning 0 deg, and the mouth is 44.2 mm, 5.4 mm to spare on the way in"
ECHO: "port fit: ph_probe's collet reaches 38.8 mm from the axis leaning 0 deg, and the mouth is 44.2 mm, 5.4 mm to spare on the way in"
ECHO: "sparge support drilling: a support tube vents through a hole drilled between 37.9375 and 63.7446 mm from its top end (past the lid's inner face, short of the culture); nearer the first is better"
ECHO: "sparge support: 3 tubes at [180, 60, 300] deg; 169.388 mm of free support tube and 163.252 mm of feed, so a support is 1.02338 N/mm, 0.977155 mm of sway per newton against 1.25 mm to the draft tube"
ECHO: "sparge riser: 4 x 3 mm tube; the feed is 213.189 mm and each support 219.326 mm (the feed socket sits 6.13634 mm higher); 14.9375 mm proud of its port, 12 mm inside the socket, 0.4 mm of slack through the port's bore"
ECHO: "sparge riser seal: 4x1.5 EPDM (8785N364) in each of 3 ports, at 0% stretch and 18% squeeze; without it each port is a 2.63894 mm2 hole into the headspace"
ECHO: "dosing: Kamoer NKP-DC-S10B pulls 3 x 5 mm tube over 1 riser of 4 mm, 1 mm of interference over 14.9375 mm of stub"
ECHO: "sparge tube stock: 50415K21, 316 SS welded, hard temper; cut 1 x 213.189 mm and 2 x 219.326 mm = 651.841 mm from a 1000 mm length, leaving 348.159 mm spare"
ECHO: "sparge back-pressure: 159.045 mm of culture over the ring is 1557.42 Pa, plus 96 Pa of capillary = 1653.42 Pa the gas supply has to beat before anything bubbles"
ECHO: "gas line losses: filter 2506.4 Pa (extrapolated), check valve 1262.76 Pa (1241 to crack) and riser 23.5017 Pa at 0.726494 L/min, on top of the vessel's 1653.42 and 11.9175 Pa on the way back out (the vent slot and up to 63.7446 mm of tube); the pump beats 5458 Pa, and the filter alone is 1.51589x the vessel"
ECHO: "gas supply: ReSun 35W settles at 6.10184 L/min against this line, where 0.726494 L/min is wanted, so a throttle has to drop 21240.2 Pa on top of the line's own (not the 51.8604 L/min a back pressure held at the design point suggests)"
ECHO: "gas exhaust: nothing filters the way out; the headspace vents through a support tube to the room. An outlet filter may cost at most 29.2366 kPa per L/min before 0.726494 L/min stops being reachable, 8.47439 of what the inlet filter costs"
ECHO: "gas exhaust slot: a slot of the tube's own 7.06858 mm2 bore costs 4.89041 Pa at 0.726494 L/min, and the tube above it 4.18218-7.02713 Pa over the 37.9375-63.7446 mm drilling window, together 0.0427142-0.0561083% of the 21240.2 Pa the exhaust has to spend; file past 0.107257 mm2 (a 0.369545 mm round hole), which the bore clears 65.9033x over"
ECHO: "gas throttle: a valve of Cv 0.00377143 passes 0.726494 L/min at that drop; sold Cv should be 2-4x it so the setting sits mid-travel"
ECHO: "gas metering: 0.1-0.5 vvm on 1.45299 L is 0.145299-0.726494 L/min, so a 0-1 L/min rotameter"
ECHO: "gas supply: ReSun 35W's free flow and dead head cannot be simultaneous, together 83.5714% of its electrical input; they are read as the ends of its curve"
ECHO: "port interfaces: all 6 ports on std, so one face o-ring covers the lid and any port takes any function; the worst adjacent pair measures 1.4 mm against a 1 mm floor"
ECHO: "port layout: 6 ports on a 59.2 mm circle, 29.6 mm chord; the full set fits a mouth from 142.025 mm (142.025 uniform std), the reduced set from 78.0017 mm (87.6038 uniform std); this jar's is 88.4"
ECHO: "lid gasket: cut 88.4 x 98.4 mm from EPDM 1/16 60A (1.5875 mm), recess 1.19062 mm deep (25% squeeze); 9 per 304.8 x 304.8 mm sheet"
ECHO: "lid lip: crowned on a 2 mm arc standing 0 mm proud of the wall, so the gasket covers the lip and the crown sinks 0.396875 mm into it; 5 mm of gasket, 2.39164 mm of contact"
ECHO: "lid gasket load: 2.39164 mm of contact, 1335.79 N to hold 25% squeeze, 1.92407 MPa on the glass"
ECHO: "plug o-ring: AS568-152 at 2.29044% stretch; the groove takes ID 84.1032 mm down to 80.0983 mm (0-5% stretch)"

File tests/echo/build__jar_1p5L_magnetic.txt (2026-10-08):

ECHO: "build: jar_1p5L_112x215, magnetic drive, 86.5% of capacity; designated lid centre plain"
ECHO: "joint: 8 posts at 51.2472 mm on a 130.5 mm circle"
ECHO: "joint load: 1335.79 N of gasket seating over 8 posts = 166.974 N each, on M8 bolts and M8 rods"
ECHO: "joint tightening: 114.3 deg past snug on each of the 8 nuts (0.396875 mm of gasket travel on a 1.25 mm pitch); the printed flange creeps, so go back to them"
ECHO: "reactor envelope: 149.1 mm dia x 248.515 mm tall"
ECHO: "printers: the widest printed part is a 149.1 mm disc (lid, base, top base); registered printers that take it: ["prusa_mk3s", "prusa_core_one", "voron_250", "bambu_x1c", "prusa_core_one_l", "bambu_h2d", "sovol_sv08", "voron_350", "prusa_xl"]"
ECHO: "base wall thickness: ", 3.7, " cm"
ECHO: "threaded rod length: ", 232, " mm"
ECHO: "base floor: jar lands at r", 48.25, "mm, ring spans r", 33.25, "to r", 56.05, "mm"
ECHO: "light pockets: end at z 218; stopping 10.1153 mm under the top base"
ECHO: "lights: 6 tubes - 3 in each of 2 quadrants - on a light that comes 4 to a cord, so 2 cords and 2 tubes left over"
ECHO: "fan joint: 4 x M3 x 20 mm down through the fan into nuts in 3.2 mm hex pockets at the carrier's bottom face, 2.8 mm of carrier over them; the head stands 1.65 mm on the fan, 3.26676 mm under the glass"
ECHO: "fan joint, head down: an M3 x 20 mm cap screw up from the pocket to a nut on the fan stands 3.8 mm over that nut, 1.28324 mm into it - shorten the screw, or build it the other way up"
ECHO: "stir drive: fan40x11 in a 66.1 mm carrier 17 mm tall, its top 0.515337 mm under the landing plane, hung on its ear 8 mm off the bottom face; the fan is turned 45 deg to put a flat on the slot's bearing, and the lead leaves its 8 mm notch there for the 14.55 mm slot at 135 deg"
ECHO: "stir magnets: 2 x MAG5x8 on the 25 mm hub at 13 mm pitch, faces 1 mm under the punt and 5 mm from the floor inside"
ECHO: "stir bar: 38x8 centred on the 15 mm punt plateau, overhanging it by 11.5 mm each end; sweeps r 19 under the sparge arm, 15.7463 mm over it; the sparger is still placed on the shaft drive's impeller"
ECHO: "DO probe lean: 4.5 deg of a 4.5 deg ceiling"
ECHO: "culture: 1.45299 L standing 168.193 mm deep, 86.5% of the 1.67975 L capacity and 82.4475% of the 204 mm internal height"
ECHO: "culture headspace: 0.226767 L of gas space at 86.5% of capacity, above the usual 0.8 by 6.5 points"
ECHO: "thermocouple: 3872K129 on 1/8 NPT, tip 134.9 mm below the lid at 50% engagement, 91.0929 mm under the surface with 84.1 mm to the floor; 127.4 to 142.4 mm over the engagement range"
ECHO: "probe: do_probe carries DO lab g2, reaching 151.597 mm, tip 107.79 mm under the surface with 67.4033 mm to the floor, leaning 4.5 deg"
ECHO: "probe: ph_probe carries pH lab g2, reaching 197.438 mm, tip 153.63 mm under the surface with 21.5624 mm to the floor, leaning 0 deg"
ECHO: "baffles: none on this lid, so the vessel is unbaffled and will swirl rather than mix"
ECHO: "sparge arm: from the air inlet's riser at r 29.6 in to r 9, 27.2099 mm off the floor, 10 mm under the lower impeller's blades; at 0.5 vvm that is 0.726494 L/min"
ECHO: "sparge arm: 1 holes of 3 mm along 5 mm at 1.66667 hole diameters, 1.71296 m/s each; bubbles 5.09817 mm at formation, 174.518 a second; the 4 mm bore carries 0.963542 m/s, open area ratio 0.5625"
ECHO: "WARNING sparge arm: extrapolated on ["hole pitch"]"
ECHO: "sparge arm socket: 4.2 mm bore, 0.2 mm over the riser, 12 mm deep in a 10.2 mm boss of the tube's own section; one M4x6 316 (92029A142) through its 3 mm wall bites the riser by 3 mm; the end is open through a 3.3 mm pilot in 6 mm of stock and plugged by another"
ECHO: "sparge holes: capillary 96 Pa to launch a bubble against 4.89041 Pa to push gas through, so the holes will not all flow evenly, which Rewatkar & Joshi find does not matter near the impeller"
ECHO: "port fit: do_probe's collet reaches 43.8842 mm from the axis leaning 4.5 deg, and the mouth is 44.2 mm, 0.315836 mm to spare on the way in"
ECHO: "port fit: ph_probe's collet reaches 38.8 mm from the axis leaning 0 deg, and the mouth is 44.2 mm, 5.4 mm to spare on the way in"
ECHO: "sparge support drilling: a support tube vents through a hole drilled between 37.9375 and 63.7446 mm from its top end (past the lid's inner face, short of the culture); nearer the first is better"
ECHO: "sparge riser: 4 x 3 mm tube; the feed is 202.128 mm and each dosing or vent tube 166.269 mm (the feed socket sits 35.8587 mm lower); 14.9375 mm proud of its port, 12 mm inside the socket, 0.4 mm of slack through the port's bore"
ECHO: "sparge riser seal: 4x1.5 EPDM (8785N364) in each of 3 ports, at 0% stretch and 18% squeeze; without it each port is a 2.63894 mm2 hole into the headspace"
ECHO: "dosing: Kamoer NKP-DC-S10B pulls 3 x 5 mm tube over 1 riser of 4 mm, 1 mm of interference over 14.9375 mm of stub"
ECHO: "sparge tube stock: 50415K21, 316 SS welded, hard temper; cut 1 x 202.128 mm and 2 x 166.269 mm = 534.665 mm from a 1000 mm length, leaving 465.335 mm spare"
ECHO: "sparge back-pressure: 147.983 mm of culture over the arm is 1449.1 Pa, plus 96 Pa of capillary = 1545.1 Pa the gas supply has to beat before anything bubbles"
ECHO: "gas line losses: filter 2506.4 Pa (extrapolated), check valve 1262.78 Pa (1241 to crack) and riser 22.2823 Pa at 0.726494 L/min, on top of the vessel's 1545.1 and 11.9175 Pa on the way back out (the vent slot and up to 63.7446 mm of tube); the pump beats 5348.48 Pa, and the filter alone is 1.62216x the vessel"
ECHO: "gas supply: ReSun 35W settles at 6.1318 L/min against this line, where 0.726494 L/min is wanted, so a throttle has to drop 21349.7 Pa on top of the line's own (not the 52.124 L/min a back pressure held at the design point suggests)"
ECHO: "gas exhaust: nothing filters the way out; the headspace vents through a support tube to the room. An outlet filter may cost at most 29.3874 kPa per L/min before 0.726494 L/min stops being reachable, 8.51808 of what the inlet filter costs"
ECHO: "gas exhaust slot: a slot of the tube's own 7.06858 mm2 bore costs 4.89041 Pa at 0.726494 L/min, and the tube above it 4.18218-7.02713 Pa over the 37.9375-63.7446 mm drilling window, together 0.0424951-0.0558205% of the 21349.7 Pa the exhaust has to spend; file past 0.106981 mm2 (a 0.369071 mm round hole), which the bore clears 66.073x over"
ECHO: "gas throttle: a valve of Cv 0.00376367 passes 0.726494 L/min at that drop; sold Cv should be 2-4x it so the setting sits mid-travel"
ECHO: "gas metering: 0.1-0.5 vvm on 1.45299 L is 0.145299-0.726494 L/min, so a 0-1 L/min rotameter"
ECHO: "gas supply: ReSun 35W's free flow and dead head cannot be simultaneous, together 83.5714% of its electrical input; they are read as the ends of its curve"
ECHO: "port interfaces: all 6 ports on std, so one face o-ring covers the lid and any port takes any function; the worst adjacent pair measures 1.4 mm against a 1 mm floor"
ECHO: "port layout: 6 ports on a 59.2 mm circle, 29.6 mm chord; the full set fits a mouth from 142.025 mm (142.025 uniform std), the reduced set from 78.0017 mm (87.6038 uniform std); this jar's is 88.4"
ECHO: "lid gasket: cut 88.4 x 98.4 mm from EPDM 1/16 60A (1.5875 mm), recess 1.19062 mm deep (25% squeeze); 9 per 304.8 x 304.8 mm sheet"
ECHO: "lid lip: crowned on a 2 mm arc standing 0 mm proud of the wall, so the gasket covers the lip and the crown sinks 0.396875 mm into it; 5 mm of gasket, 2.39164 mm of contact"
ECHO: "lid gasket load: 2.39164 mm of contact, 1335.79 N to hold 25% squeeze, 1.92407 MPa on the glass"
ECHO: "plug o-ring: AS568-152 at 2.29044% stretch; the groove takes ID 84.1032 mm down to 80.0983 mm (0-5% stretch)"

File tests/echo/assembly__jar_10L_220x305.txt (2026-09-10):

ECHO: "joint: ", 12, " posts at ", 62.5177, " mm on a ", 238.8, " mm circle"
ECHO: "joint load: 4212.27 N of gasket seating over 12 posts = 351.023 N each, on M8 bolts and M8 rods"
ECHO: "joint tightening: 114.3 deg past snug on each of the 12 nuts, all of which sit on top of the lid - 0.396875 mm of gasket travel on a 1.25 mm pitch. The printed flange takes a little more and then creeps, so go back to them."
ECHO: "reactor envelope: ", 257.4, " mm dia x ", 571.25, " mm tall"
ECHO: "printers: the widest printed part is a 257.4 mm disc - the lid, and the frame's base and top base - so this build wants a bed that takes a disc that wide. Registered printers that do: ["prusa_core_one_l", "bambu_h2d", "sovol_sv08", "voron_350", "prusa_xl"]"
ECHO: "base wall thickness: ", 3.7, " cm"
ECHO: "base floor: jar lands at r", 97.5, "mm, ring spans r", 82.5, "to r", 110.2, "mm"
ECHO: "lights: 6 tubes - 3 in each of 2 quadrants - on a light that comes 3 to a cord, so 2 cords and nothing spare"
ECHO: "DO probe lean: 4.5 deg - the most of 4.5 deg this jar allows, which is the whole of it"
ECHO: "vessel fit: a 94.5 mm impeller is feasible in mouths 127.75 to anything wider (nothing bounds it above); this jar's is 142.2"
ECHO: "impeller: 94.5 mm in a 210 mm bore, D/T 0.45 (band 0.3-0.5, axial 0.4-0.5); spacing 1 D (band 1-2)"
ECHO: "impeller clearance: centreline 85.05 mm off the floor = 0.9 D (Oldshue allows 1-2), C/T 0.405; 76.9536 mm under the lower impeller and 51.6285 mm (0.546334 D) of culture over the upper"
ECHO: "impeller count: 2 on 2.4791 impeller diameters of liquid (H/T 1.11559), where the spacing band allows 0.23955 < n < 1.4791 - so this column is SHORT for a pair, and the second impeller is one the spacing would not add. It costs the coverage above: 0.546334 D against the 0.5 D floor"
ECHO: "impeller clearance: 0.9 D sits below the 1-2 D Oldshue allows, but that allowance is for fluidfoils and this is a pbt_45_4. The guidance that fits it is Fořt's, who measured better hydraulic efficiency at C/D 1.0 than 0.5; his correlation's own C/D limit is 1.0 and coverage over the upper impeller binds at 0.946334 D. See docs/agitation.md."
ECHO: "impeller pumping: shaft turns counter-clockwise seen from above, so the lower impeller pumps UP and the upper DOWN and the pair CONVERGES on the 70.3073 mm gap between them"
ECHO: "impeller set screws: 2 x M4x6 316 (92029A142) at [0, 120] deg, 5.8 mm of thread in a 3.3 mm tap hole, through a 8 mm collar above the blades"
ECHO: "culture: 8.22105 L standing 234.275 mm deep, 86.5% of capacity and 79.4152% of the 295 mm internal height - DERIVED from culture_fill_fraction, a fraction of what this jar holds, so it scales to every registered vessel. The jar holds 9.5041 L brim full, and a cylinder on the 210 mm bore would have called this fill 8.11436 L"
ECHO: "culture headspace: 1.28305 L of gas space, filling 86.5% of capacity - ABOVE the 0.8 this project's own note called usual, by 6.5 points"
ECHO: "impeller: pbt_45_4 Po 1.49679 and flow number 0.891811 from Medek's correlation at 45 deg, extrapolated on ["T/D", "H/T"]"
ECHO: "drive no-load 420 rpm: Re 62274.7, tip 2.07816 m/s, 3.86217 W into 8.22105 L = 469.791 W/m3 mean, 68.9734 W/kg peak, pair under 0.175624 Nm of 0.4903 Nm rated"
ECHO: "drive rated 320 rpm: Re 47447.4, tip 1.58336 m/s, 1.70818 W into 8.22105 L = 207.781 W/m3 mean, 30.5059 W/kg peak, pair under 0.10195 Nm of 0.4903 Nm rated"
ECHO: "thermocouple: 1245N31 on 1/2 NPT, tip 137.4 mm below the lid at 50% thread engagement - 68.6749 mm under the surface with 170.6 mm to the floor. Not threaded at all to fully in spans 127.4 to 147.4 mm, which is the band the asserts test."
ECHO: "probe: do_probe carries DO lab g2, reaching 151.597 mm - tip 82.8716 mm under the surface with 156.403 mm to the floor, leaning 4.5 deg"
ECHO: "probe: ph_probe carries pH lab g2, reaching 197.438 mm - tip 128.713 mm under the surface with 110.562 mm to the floor, leaning 0 deg"
ECHO: "transfer no-load 420 rpm: blend to 95% in 3.49702 s; kLa 0.013547 1/s coalescing, 0.0427176 1/s not, at 1.97796 mm/s superficial gas"
ECHO: "transfer rated 320 rpm: blend to 95% in 4.58984 s; kLa 0.00977518 1/s coalescing, 0.0241323 1/s not, at 1.97796 mm/s superficial gas"
ECHO: "transfer: kLa is van't Riet's air-water correlation, fitted over 500-10000 W/m3, and this vessel runs 207.781. Read it as an order of magnitude, not a number."
ECHO: "transfer: blend time is Ruszkowski's, fitted on 0.01-10 m3 fully baffled, and this is 0.00822105 m3. It reproduces Hall's published table at a tenth of that, so the extrapolation is a short one."
ECHO: "drive encoder: 12 ppr x 2 channels through 14:1 = 672 counts per output turn, resolving 0.892857 rpm over 100 ms"
ECHO: "shaft: 8x400_316 (1265K66) 7.995-8 mm in a 8 mm bore: -0.007 to 0.005 mm"
ECHO: "motor mount height: ", 12.2, " cm"
ECHO: "bearing seal: 22x1.5 EPDM on the 608's 22 mm rim at 0% stretch, in a groove to 24.46 mm - 18% radial squeeze, and 6.02 mm from the nearest mount insert"
ECHO: "motor mount: 4 x M4x4.7 18-8 inserts on a 42.8 mm circle, 8 mm M4 screws, 13.25 mm of lid left under them, 6.02 mm to the bearing pocket"
ECHO: "baffles: 4 x 10.3454 x 280 mm (280 mm clears the floor), 229.275 mm of that submerged; 0.578548 of Oldshue's four-at-T/12 full-depth reference area"
ECHO: "WARNING baffles: 0.578548 of the reference projected area. Depth is spent - these already hang to the floor limit. Going to 6 plates, the next count that spaces equally on 12 ports, would give 0.867821. Under-baffling lets the vessel swirl rather than mix; see docs/agitation.md."
ECHO: "baffle plate: 0.777097 N each, deflecting 1.94153 mm at the tip (0.27611 mm of it the joints); first mode 19.1606 Hz against 7 Hz shaft and 28 Hz blade passing at 420 rpm - that mode is the solid plate, the joints soften it"
ECHO: "baffle print: 2 pieces of 140 mm, tallest standing 163 mm against a 200 mm cap - which is how slender a piece may be, NOT how tall a bed is; see assembly.scad for what can actually print this; the dovetail leaves 4.2 mm of 10 crossing each joint, 0.074088 of the plate's second moment"
ECHO: "baffle clearance: 4.07731 mm nominal to the impeller, less 2.27722 mm the coupling's 0.2 mm of play allows at the lower impeller = 1.80009 mm running"
ECHO: "WARNING baffle plate: 1.94153 mm of tip deflection is over a tenth of the 10.3454 mm plate. It is bending away from the swirl rather than blocking it; thicken it - stiffness goes as the cube of thickness and the lock bore allows more."
ECHO: "baffle resonance: the 19.1606 Hz mode is crossed by the shaft at 1149.64 rpm and by blade passing at 287.409 rpm, against a 320-420 rpm band. Neither is a speed this drive is asked to hold - the nearest clears the band by 10.1846% - though it passes through on the way up, which is a transient rather than a duty."
ECHO: "sparge ring: 132.773 mm = 1.405 D (band 1-2, equal-swept-volume 1.41421), 136.3 mm off the floor - 51.25 above the lower impeller and 43.25 below the upper"
ECHO: "sparge ring fits: 1.25 mm to the baffles, 1.25 mm to the jar's mouth on the way in. A 6.4 mm tube reaching 6.92731 across its corners, on a 4 mm bore of 12.5664 mm2"
ECHO: "sparger: 1 ring(s) at [66.3863] mm carrying [8] holes of 3 mm - 8 in all, at 1.2115 m/s through them"
ECHO: "sparger bubbles: 5.09817 mm at formation, 987.426 a second (specific area needs a holdup)"
ECHO: "sparger feed run: 4 mm bore at 1 path carrying 5.45175 m/s; its 17.8924 Pa of velocity head against 2.44622 Pa at a hole, open area ratio 4.5 - every hole is downstream of this one bore"
ECHO: "sparger rings: [2.72588] m/s at 2 path(s) each, open area ratio [2.25]; [4.4731] Pa of velocity head - open area reaches 4.5, ABOVE 1, so the holes compete with their own supply"
ECHO: "sparger envelope: r [62.9227, 69.85] mm, which is what has to clear the baffles and pass the mouth"
ECHO: "sparger pitch: [17.3799] hole diameters between holes, against a 3 floor that is reasoned, not cited"
ECHO: "WARNING sparger: extrapolated on ["open area", "bore velocity"]"
ECHO: "sparge holes: 8 x 3 mm at 52.1397 mm spacing; at 0.5 vvm that is 4.11052 L/min through them at 1.2115 m/s"
ECHO: "sparge holes: capillary 96 Pa to launch a bubble against 2.44622 Pa to push gas through, so the holes will not all flow evenly - which Rewatkar & Joshi find does not matter near the impeller."
ECHO: "sparge ring: the ring is what caps the baffles here, at 10.3454 mm - they would otherwise be 14.5 mm. Room outside a baffle does not grow with the mouth, so this is the trade on every jar."
ECHO: "reach clearance: do_probe's tip passes the upper impeller with 11.2869 mm of radial room, over the -136.546 to -120.354 mm the two share"
ECHO: "reach clearance: ph_probe's tip passes the upper impeller with 3.25 mm of radial room, over the -136.546 to -120.354 mm the two share"
ECHO: "reach clearance: ph_probe's tip passes the sparge ring with 0.42269 mm of radial room, over the -175.164 to -168.236 mm the two share"
ECHO: "reach clearance: the thermocouple passes the upper impeller with 7.6625 mm of radial room, over the -136.546 to -120.354 mm the two share"
ECHO: "DO probe feed no-load 420 rpm: the vessel turns over at 190.725 mm/s mean and the probe needs 8.84194 mm/s past its face - 21.5705x. MEAN, not local: it says the tank moves, not that this corner of it does"
ECHO: "DO probe feed rated 320 rpm: the vessel turns over at 145.314 mm/s mean and the probe needs 8.84194 mm/s past its face - 16.4346x. MEAN, not local: it says the tank moves, not that this corner of it does"
ECHO: "DO probe in the gas: its face sits 20.574 mm above the sparge ring's centreline and 0.590895 mm off its radius. Where the bubbles actually go is a bench question - the holes point inward, toward the impeller, and the impeller disperses what it catches - so nothing here models it."
ECHO: "WARNING DO probe: its face overlaps the sparge ring's own radius and hangs 20.574 mm over it. A galvanic probe reads HIGH with a bubble on the membrane and low with none moving past, so this is the one placement that can be wrong in both directions at once. See TODO.md."
ECHO: "port fit: do_probe's collet reaches 70.7842 mm from the axis leaning 4.5 deg, and the mouth is 71.1 mm - 0.315836 mm to spare on the way in"
ECHO: "port fit: ph_probe's collet reaches 65.7 mm from the axis leaning 0 deg, and the mouth is 71.1 mm - 5.4 mm to spare on the way in"
ECHO: "sparge support drilling: a support tube vents through a hole drilled between 37.9375 and 88.6626 mm from its TOP end - past the lid's inner face, short of the culture. Nearer the first number is better; the headspace is there for foam and foam finds the lowest hole. A tube meant to discharge INTO the culture instead is drilled past the second."
ECHO: "sparge support: 5 tubes at [240, 0, 180, 270, 330] deg; the 4 supports have 142.236 mm of free tube and the feed 136.1 mm, so a support is 1.72844 N/mm, so 0.578556 mm of sway per newton against 1.25 mm to the baffles"
ECHO: "sparge riser: 4 x 3 mm tube; the feed is 182.037 mm and each support 188.174 mm - the feed socket sits 6.13634 mm higher, so its tube is shorter by the same. 14.9375 mm proud of its port for a hose, down to 8 mm inside the socket; 0.4 mm of slack through the port's bore"
ECHO: "sparge riser seal: 4x1.5 EPDM (8785N364) in each of 5 ports, at 0% stretch and 18% squeeze - without it each port is a 2.63894 mm2 hole into the headspace, and the sterile filter only covers the way in"
ECHO: "dosing: Kamoer NKP-DC-S10B pulls 3 x 5 mm tube over 2 risers of 4 mm - 1 mm of interference over 14.9375 mm of stub, which is what grips it"
ECHO: "sparge tube stock: 50415K21, 316 SS welded, hard temper; cut 1 x 182.037 mm and 4 x 188.174 mm = 934.733 mm from a 1000 mm length, leaving 65.2671 mm spare"
ECHO: "sparge back-pressure: 102.975 mm of culture over the ring is 1008.37 Pa, plus 96 Pa of capillary = 1104.37 Pa the gas supply has to beat before anything bubbles"
ECHO: "gas line losses: filter 14181.3 Pa (EXTRAPOLATED, not measured), check valve 1941.18 Pa (1241 of it just to crack) and riser 113.543 Pa at 4.11052 L/min, on top of the vessel's 1104.37 - so the pump beats 17340.4 Pa, and the filter alone is 12.8411x the vessel"
ECHO: "gas supply: ReSun 35W settles at 6.0513 L/min against this line, where 4.11052 L/min is wanted - so a throttle has to drop 7952.15 Pa on top of the line's own. NOT the 23.2546 L/min a back pressure held at the design point suggests: the filter is linear in flow, so asking for more raises the line, and that figure prices it at a flow nobody is asking for"
ECHO: "gas exhaust: NOTHING FILTERS THE WAY OUT - the headspace vents through a support tube to the room, so the 0.2 um filter on the inlet guards one direction of two. An outlet filter may cost at most 1.93458 kPa per L/min before 4.11052 L/min stops being reachable, which is 0.560749 of what the inlet filter costs - so a second one of those will not do."
ECHO: "gas exhaust slot: air_out vents through a hand-cut hole, so its SIZE is the one restriction on the way out that nothing here draws. A slot of the tube's own 7.06858 mm2 bore costs 156.558 Pa at 4.11052 L/min, and the tube above it another 23.6629-55.3019 Pa over the 37.9375-88.6626 mm drilling window - together 2.26632-2.66418% of the 7952.15 Pa the exhaust has to spend. FILE PAST 0.991809 mm2 - a round hole of 1.12375 mm - or the slot alone is the whole of it. The bore's own area clears that 7.12696x over."
ECHO: "gas throttle: a valve of Cv 0.0330828 passes 4.11052 L/min at that drop. Sold Cv should be 2-4x it, so the setting sits mid-travel rather than at either stop"
ECHO: "gas metering: 0.1-0.5 vvm on 8.22105 L is 0.822105-4.11052 L/min, so a 0-5 L/min rotameter"
ECHO: "gas supply: ReSun 35W's free flow and dead head cannot be simultaneous - together they are 83.5714% of its electrical input. They are the ends of its curve, which is how this reads them."
ECHO: "gas against the impeller: axial pumping needs 8x the gas stream's power to hold its flow pattern, which at 420 rpm caps aeration at 1.53587 vvm"
ECHO: "port interfaces: all 12 ports on std - so one face o-ring covers the lid and any port takes any function. It is free here: the worst adjacent pair is std-against-std whatever the small ports do, and it measures 1.04655 mm against a 1 mm floor"
ECHO: "eccentricity: the mount leaves 12.4 mm of offset, e/T 0.0590476 against Hall's measured 0.2 - worth 23.5472% of the centred blend time on Karcz's up-pumping branch, but only to an unbaffled vessel and this one carries 4 baffles. Extrapolated on ["D/T", "H/T", "scale", "baffle count", "pumping mode", "impeller type"]"
ECHO: "lid gasket: cut 142.2 x 158.2 mm from EPDM 1/16 60A (1.5875 mm), recess 1.19062 mm deep (25% squeeze); 1 per 304.8 x 304.8 mm sheet"
ECHO: "lid lip: crowned on a 3.5 mm arc standing 2 mm proud of the wall - no flat to seat on, so the gasket covers the lip and the crown sinks 0.396875 mm into it; 8 mm of gasket, 3.23766 mm of contact"
ECHO: "lid gasket load: 3.23766 mm of contact, 4212.27 N to hold 25% squeeze, 2.77566 MPa on the glass"
ECHO: "plug o-ring: AS568-160 at 3.67103% stretch. Groove takes ID 137.903 mm / 5.42926 in down to 131.336 mm / 5.17072 in (0-5% stretch)"

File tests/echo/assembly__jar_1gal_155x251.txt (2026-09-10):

ECHO: "joint: ", 12, " posts at ", 45.5793, " mm on a ", 174.1, " mm circle"
ECHO: "joint load: 1034.92 N of gasket seating over 12 posts = 86.2437 N each, on M8 bolts and M8 rods"
ECHO: "joint tightening: 114.3 deg past snug on each of the 12 nuts, all of which sit on top of the lid - 0.396875 mm of gasket travel on a 1.25 mm pitch. The printed flange takes a little more and then creeps, so go back to them."
ECHO: "reactor envelope: ", 192.7, " mm dia x ", 527.5, " mm tall"
ECHO: "printers: the widest printed part is a 192.7 mm disc - the lid, and the frame's base and top base - so this build wants a bed that takes a disc that wide. Registered printers that do: ["prusa_mk3s", "prusa_core_one", "voron_250", "bambu_x1c", "prusa_core_one_l", "bambu_h2d", "sovol_sv08", "voron_350", "prusa_xl"]"
ECHO: "base wall thickness: ", 3.7, " cm"
ECHO: "base floor: jar lands at r", 63.65, "mm, ring spans r", 48.65, "to r", 77.85, "mm"
ECHO: "lights: 6 tubes - 3 in each of 2 quadrants - on a light that comes 4 to a cord, so 2 cords and 2 tubes left over"
ECHO: "DO probe lean: 4.5 deg - the most of 4.5 deg this jar allows, which is the whole of it"
ECHO: "vessel fit: a 67.185 mm impeller is feasible in mouths 78 to anything wider (nothing bounds it above); this jar's is 95.8"
ECHO: "impeller: 67.185 mm in a 149.3 mm bore, D/T 0.45 (band 0.3-0.5, axial 0.4-0.5); spacing 1 D (band 1-2)"
ECHO: "impeller clearance: centreline 60.4665 mm off the floor = 0.9 D (Oldshue allows 1-2), C/T 0.405; 54.3016 mm under the lower impeller and 60.7734 mm (0.904568 D) of culture over the upper"
ECHO: "impeller count: 2 on 2.80702 impeller diameters of liquid (H/T 1.26316), where the spacing band allows 0.403511 < n < 1.80702 - so this column is SHORT for a pair, and the second impeller is one the spacing would not add. It costs the coverage above: 0.904568 D against the 0.5 D floor"
ECHO: "impeller clearance: 0.9 D sits below the 1-2 D Oldshue allows, but that allowance is for fluidfoils and this is a pbt_45_4. The guidance that fits it is Fořt's, who measured better hydraulic efficiency at C/D 1.0 than 0.5; his correlation's own C/D limit is 1.0 and coverage over the upper impeller binds at 1.30457 D. See docs/agitation.md."
ECHO: "impeller pumping: shaft turns counter-clockwise seen from above, so the lower impeller pumps UP and the upper DOWN and the pair CONVERGES on the 46.8552 mm gap between them"
ECHO: "impeller set screws: 2 x M4x6 316 (92029A142) at [0, 120] deg, 5.8 mm of thread in a 3.3 mm tap hole, through a 8 mm collar above the blades"
ECHO: "culture: 3.34624 L standing 188.59 mm deep, 86.5% of capacity and 77.9297% of the 242 mm internal height - DERIVED from culture_fill_fraction, a fraction of what this jar holds, so it scales to every registered vessel. The jar holds 3.86848 L brim full, and a cylinder on the 149.3 mm bore would have called this fill 3.30162 L"
ECHO: "culture headspace: 0.522245 L of gas space, filling 86.5% of capacity - ABOVE the 0.8 this project's own note called usual, by 6.5 points"
ECHO: "impeller: pbt_45_4 Po 1.52305 and flow number 0.920058 from Medek's correlation at 45 deg, extrapolated on ["T/D", "H/T", "baffle count"]"
ECHO: "drive no-load 420 rpm: Re 31476.9, tip 1.47748 m/s, 0.713818 W into 3.34624 L = 213.32 W/m3 mean, 35.3206 W/kg peak, pair under 0.0324593 Nm of 0.4903 Nm rated"
ECHO: "drive rated 320 rpm: Re 23982.4, tip 1.1257 m/s, 0.315711 W into 3.34624 L = 94.3481 W/m3 mean, 15.6218 W/kg peak, pair under 0.0188426 Nm of 0.4903 Nm rated"
ECHO: "thermocouple: 3872K129 on 1/8 NPT, tip 134.9 mm below the lid at 50% thread engagement - 73.4898 mm under the surface with 121.1 mm to the floor. Not threaded at all to fully in spans 127.4 to 142.4 mm, which is the band the asserts test."
ECHO: "probe: do_probe carries DO lab g2, reaching 151.597 mm - tip 90.1865 mm under the surface with 104.403 mm to the floor, leaning 4.5 deg"
ECHO: "probe: ph_probe carries pH lab g2, reaching 197.438 mm - tip 136.027 mm under the surface with 58.5624 mm to the floor, leaning 0 deg"
ECHO: "transfer no-load 420 rpm: blend to 95% in 3.62424 s; kLa 0.00886479 1/s coalescing, 0.0235388 1/s not, at 1.59282 mm/s superficial gas"
ECHO: "transfer rated 320 rpm: blend to 95% in 4.75681 s; kLa 0.0063966 1/s coalescing, 0.0132977 1/s not, at 1.59282 mm/s superficial gas"
ECHO: "transfer: kLa is van't Riet's air-water correlation, fitted over 500-10000 W/m3, and this vessel runs 94.3481. Read it as an order of magnitude, not a number."
ECHO: "transfer: blend time is Ruszkowski's, fitted on 0.01-10 m3 fully baffled, and this is 0.00334624 m3. It reproduces Hall's published table at a tenth of that, so the extrapolation is a short one."
ECHO: "drive encoder: 12 ppr x 2 channels through 14:1 = 672 counts per output turn, resolving 0.892857 rpm over 100 ms"
ECHO: "shaft: 8x400_316 (1265K66) 7.995-8 mm in a 8 mm bore: -0.007 to 0.005 mm"
ECHO: "WARNING motor mount: 3.125 diameters tall. The shaft is already the shortest registered row that reaches - 400 mm against the 257.5 this vessel needs. The registry steps 200/400/600/800, so the excess is the step, not a choice; a cut between them would take it out."
ECHO: "motor mount height: ", 17.5, " cm"
ECHO: "bearing seal: 22x1.5 EPDM on the 608's 22 mm rim at 0% stretch, in a groove to 24.46 mm - 18% radial squeeze, and 6.02 mm from the nearest mount insert"
ECHO: "motor mount: 4 x M4x4.7 18-8 inserts on a 42.8 mm circle, 8 mm M4 screws, 13.25 mm of lid left under them, 6.02 mm to the bearing pocket"
ECHO: "baffles: none on this lid, so the vessel is unbaffled and will swirl rather than mix"
ECHO: "sparge ring: 86.3727 mm = 1.28559 D (band 1-2, equal-swept-volume 1.41421), 98.059 mm off the floor - 37.5925 above the lower impeller and 29.5925 below the upper"
ECHO: "sparge ring fits: 8.71519 mm to the baffles, 1.25 mm to the jar's mouth on the way in. A 6.4 mm tube reaching 6.92731 across its corners, on a 4 mm bore of 12.5664 mm2"
ECHO: "sparger: 1 ring(s) at [43.1863] mm carrying [8] holes of 3 mm - 8 in all, at 0.49312 m/s through them"
ECHO: "sparger bubbles: 5.09817 mm at formation, 401.915 a second (specific area needs a holdup)"
ECHO: "sparger feed run: 4 mm bore at 1 path carrying 2.21904 m/s; its 2.96433 Pa of velocity head against 0.405279 Pa at a hole, open area ratio 4.5 - every hole is downstream of this one bore"
ECHO: "sparger rings: [1.10952] m/s at 2 path(s) each, open area ratio [2.25]; [0.741084] Pa of velocity head - open area reaches 4.5, ABOVE 1, so the holes compete with their own supply"
ECHO: "sparger envelope: r [39.7227, 46.65] mm, which is what has to clear the baffles and pass the mouth"
ECHO: "sparger pitch: [11.3062] hole diameters between holes, against a 3 floor that is reasoned, not cited"
ECHO: "WARNING sparger: extrapolated on ["open area", "bore velocity"]"
ECHO: "sparge holes: 8 x 3 mm at 33.9185 mm spacing; at 0.5 vvm that is 1.67312 L/min through them at 0.49312 m/s"
ECHO: "sparge holes: capillary 96 Pa to launch a bubble against 0.405279 Pa to push gas through, so the holes will not all flow evenly - which Rewatkar & Joshi find does not matter near the impeller."
ECHO: "reach clearance: do_probe's tip passes the upper impeller with 1.88837 mm of radial room, over the -134.513 to -122.184 mm the two share"
ECHO: "reach clearance: ph_probe's tip passes the lower impeller with -6.2925 mm of radial room, over the -201.698 to -189.369 mm the two share"
ERROR: Assertion '(_gap > 0)' failed: "ph_probe's tip runs through the lower impeller by 6.2925 mm radially, over the heights they share. Both are drawn, so this is parts in the same space rather than a margin being thin." in file head.scad, line N
TRACE: called by 'assert' in file head.scad, line N
TRACE: called by 'if' in file head.scad, line N
TRACE: called by 'let' in file head.scad, line N
TRACE: called by 'for' in file head.scad, line N
TRACE: called by 'for' in file head.scad, line N
TRACE: called by 'head' in file assembly.scad, line N
TRACE: called by 'translate' in file assembly.scad, line N
TRACE: called by 'children' in file assembly.scad, line N
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

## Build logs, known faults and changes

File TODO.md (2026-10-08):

# TODO

Open work only. A finished item is deleted. What was decided, and what this project got wrong on
the way, is in `docs/decisions.md`; the reasoning behind a closed item is in the commit that
closed it and in `docs/`.

## model completeness / enhancement

- [ ] **place the bought pumps in the assembly**
  - the registry half is done: `purchased/peri_pumps.scad` carries the Kamoer NKP-DC-S10B, drawn
    as its envelope, and `head()` warns when its tube's bore will not grip the riser it goes over
  - `custom/peri_pump_frame_mount.scad`'s insert now clicks into an empty light pocket in a rib
    (a detent under the rib), but its flange still assumes the old printed head: a motor on no
    purchase list, a faceplate a snap-in Kamoer has not got. A bought unit wants a bracket for a
    67 x 55 x 41 body on that insert
  - and the frame needs somewhere to put three of them: pockets, a rail, or the electronics stand.
    Nothing else waits on it - the reference run had the dose pumps disabled

- [ ] **measured gas flow**
  - the model states a vvm and no builder can set one: the ReSun pump settles at 5.80 L/min where
    0.817-4.09 is wanted. The aeration a culture wants runs 0.1-1 vvm depending on what it is for;
    the model's band stops at 0.5, and this pump and filter reach about 0.7 on `jar_10L`, which is
    enough for now. The parts are in the BOM (Dwyer VFA-23 meter, Clippard MNV-3KP needle
    valve upstream of it; why these, `docs/procurement.md`). What is left is buying them and taking
    a reading
  - no sparger geometry waits on it: `sparge_design_vvm` appears only in echoes. The arm the stirred
    builds take runs its 3 x 3 mm holes at 3.21 m/s at 0.5 vvm on `jar_10L`, inside Barbosa's
    tested 0.4-5.4 m/s from about 0.06 to 0.84 vvm; on `jar_1gal_180` the same arm is at 8.02 m/s,
    outside it, and `head()` warns
  - CO2 is answered by a run, not a calculation: air at 0.5 vvm supports about 0.09 g/L/day on a
    30 % utilisation assumption, and the 2026-07-23 run grew CCPC 90 for 8.7 days on air alone. The
    reactor's actual CO2 utilisation is the measurable unknown, and the bigger lever on productivity

- [ ] **choose an outlet filter that fits in the budget `head()` reports**
  - the exhaust is unguarded: the headspace vents through a support tube into the room. A second
    1594522 on the outlet does not work: two put the line at 32.3 kPa against a pump that dead-heads
    at 27 and it settles at 3.17 L/min, and 0.5 vvm stops being a setting it can hold
  - `head()` reports the budget instead: at most 1.7454 kPa per L/min on `jar_10L`, 50.6 % of the
    inlet filter's slope, net of the vent slot and the tube, which are priced into the line. Set
    `sparge_outlet_filter` and `head()` prices the filter in too
  - the budget moves with the inlet filter's slope, which is extrapolated - measure that first
  - a trap or a longer tube would guard against splashback with no drop; a different sterility claim

- [ ] **measure the sterile filter's pressure drop**
  - 3.45 kPa per L/min is extrapolated from an equivalent 0.2 um PTFE disc, and is the largest
    single term in the gas budget. Area-correcting Pall's Acro 50 gives 3.02, so it sits 14 %
    conservative
  - a water manometer at two points, 1 and 2 L/min (35 and 70 cm of column), tests the slope and
    the linearity both. Not at the set flow: 14.1 kPa is 1.44 m of water
  - the operational number: the filter may rise to 21.2 kPa with the valve wide open before
    0.5 vvm is unreachable, so "fully open and it will not hold 0.5 vvm" is the replace signal

- [ ] **the tube seal goes in by hand; getting it back out is untested**
  - the 4x1.5 EPDM folds into its enclosed groove on a printed port, so the gland stands as built
  - untested on the same print: whether the steel tube pushes the ring out or nicks it going in,
    and whether the ring comes out for cleaning without a tool that scars the bore. If removal
    needs a pick, the build notes need to say so

- [ ] **re-print the ports and bench-check the gland, the flange gaps and the sparge socket**
  - the gland now carries `bayonet_gland_allowance` 0.2 (the 23x1.5 would not go into a groove cut
    at exactly its OD) and the flange lips are 1.0-1.2 mm. Neither is measured against a printer:
    print a std port, fit the rings, and key the allowance to a caliper reading. Every registered
    lid is on std now; a mini port only matters if that interface is wanted again
  - the sparge sockets are bored 0.2 mm over the 4 mm riser (`sparge_socket_allow`); nobody has
    pushed a tube into a printed one yet
  - `jar_10L` carries the twelve-port set on 0.0466 mm of slack: the worst adjacent pair is
    1.0466 mm against a `lid_flange_gap` of 1.0. The next flange lip that grows moves it to the
    six-port set
  - unpriced: whether 1.0466 mm between two 5 mm flanges is enough to get a cloth into. The lever
    is a thinner cord: a 23x1 EPDM (McMaster 8785N348, not registered) takes the groove to
    Ø25.2 at 0.25 mm of squeeze

- [ ] **model the support tubes' discharge holes, or decide not to**
  - every tube port but `air_in` is capped at its lower end and vents through a hole drilled up its
    length. `head()` reports the window (37.9-88.4 mm from the top on `jar_10L`) and `docs/build.md`
    says which end each port wants; the hole itself is a bench operation and is not drawn
  - only `air_out`'s hole has a size to meet, and `head()` prices it: the floor is 1.041 mm2 on
    `jar_10L`, 0.288 on `jar_1gal_180x197`, none on `jar_6p5gal` (its line beats the pump). A normal
    file cut clears it nearly 7x; a shallow pass that just breaks the wall does not
  - not parameterised on purpose: a default for a hand-cut window would be a guess

- [ ] **where the sparger's gas actually goes, and whether the DO probe should move**
  - only for a stirred build given the ring (`sparger_name = "ring"`), which no registered build
    takes: the stirred builds default to the arm, and the airlift hangs DO straight inside its tube
  - there the DO face sits 20.6 mm above the sparge ring's centreline and 0.59 mm off its radius on
    `jar_10L`, over a ring of bubbles in the convergence zone: the one placement that can read wrong
    both ways
  - the flow rate is not the concern (bulk mean 16x what the probe needs); the gas path is not
    modelled, and no source found gives DO placement relative to a sparger
  - a bench question: run it and see whether the DO trace is spiky. If it matters, the free
    variables are the lean and the ring's height, both parameters already

- [ ] **the baffle clears the blades now, and baffle area paid for it**
  - running clearance is +1.80009 mm (4.07731 nominal less 2.27722 of lean), after the plate
    narrowed 15.3 -> 10.3454 mm and the mouth correction took 0.4 mm of it
  - the price: reference projected area 0.856 -> 0.579 of Oldshue's four-at-T/12, 0.577 since the plates
    stop 10 mm off the glass under them, 0.433 at three plates, which gave their fourth port to a
    sampling line. Whether that is acceptable is the open question, and buying width back walks toward
    the blades. The tip ring is off and stays a flag (`docs/decisions.md`)
  - the 2.28 mm lean is a worst case - bore play alone, levered 11.4x, ignoring the flange's face
    contact - and only matters if the plate widens
  - fixes, cheapest first, costed against the old 15.3 mm plate: taper the plate's inner edge with
    depth; deepen the bayonet engagement to 36 mm (halves the lean, adds a third joint); a
    baffle-only interface row at 0.1 mm allowance (a tight bayonet twisted by hand in a jar)

## drive and aeration

Follows from the agitation work; reasoning and citations in `docs/agitation.md`.

- [ ] **two things to confirm on the drive before ordering it**
  - the encoder sheet for `motor_36pg_555pm_14_en` tabulates no gearbox length; 34.5 mm is inferred
    from the 3429 sheet at 14:1. It feeds the envelope (581.25 mm) and the cart's tiers
  - caliper the bolt circle on the printed mount: Ø28 with M4 should clear holes cut for the
    36GP's Ø27.6 / 4.2, so the new motor may drop in without a reprint

- [ ] **bench-measure the twisted paddle's power number, if it is wanted back**
  - the build runs `impeller_pbt_45_4` now; the twisted row stays registered with no Po any
    correlation reaches, and its 0.634921 width ratio is the one unsourced ratio in `impellers.scad`
  - `Po = P/(rho N^3 D^5)` from shaft power at three or four speeds in water settles it. Worth
    doing to publish the blade, not to build the reactor. Kumaresan & Joshi 2006
    (doi:10.1016/j.cej.2005.10.002) is paywalled and may say something

## exhaust condenser and humidifier

Printed from their own files, `custom/condenser_cold_finger.scad`, `custom/condenser_coil.scad` and
`custom/gl_port_cap.scad`; nothing in `head()` places them yet.

- [ ] **bench-test the condensers, then place the one that works**
  - the test: a fixed flow, 48 h, the level marked (1 mm is 34.6 mL in the 210 mm bore), room and
    culture temperature logged. The one-piece cold finger, empty and then iced, is the baseline
  - untested on a print: the `large` and `xl` bayonets and their face rings, and the coil wound on
    the former with its ends formed on the pucks at 2 to 2.4x the tube's OD, which is tight for 3003.
    Two heads have now been wrong here - the first asked for a bend no tube can make, the second put
    the tube through a puck groove narrower than the tube - so measure the formed radius before
    committing a length
  - the flow insert's printed well is the only wall between coolant and gas: water-test it first, and
    feed it by gravity or through a valve on the inlet with the outlet draining freely
  - the aluminum coil never goes through the vessel's bleach step
  - placing one in `head()` replaces the `air_out` slot and tube the gas budget prices today, and
    renders its clearance to the motor mount and the probes, which is arithmetic until then

- [ ] **fit the humidifier cap to the bottle, and set it against the condenser**
  - the rim gasket's 34 mm bore is an estimate: caliper the bottle's rim. Try a short `din168_nut`
    ring on the bottle's thread before printing the whole cap
  - a condenser that cools the exhaust below the humidified inlet's dew point makes the culture gain
    water, so the two are set together, not each to its own limit

## alternative agitation modes

`jar_1p5L` and `jar_1gal_155` cannot carry a top-entry drive at any mount size, nor four baffles
beside two Ø16 probes at any port count, so both are registered as airlifts, and both with the
magnetic drive on a plain lid. Why, and what the three modes are, is
`docs/agitation.md` section 5.

- [ ] **the airlift is modelled; what is left is the bench**
  - `drive_name = "airlift"` builds it on `jar_1p5L` and `jar_1gal_155`: a clear draft tube on
    three feet, sparged inside by the ring, which centres it. `docs/build.md` has the assembly
  - measure the loop: a dye pulse or a float gives the circulation time and the downcomer's
    velocity, which no correlation in `docs/references.md` reaches at under 0.2 m tall
  - watch the DO reading hanging straight: the lean it no longer has was for a shaft's shadow, and
    the riser should carry flow past it, but that is the bench's to confirm
  - how it is held: the ring centres it, to 1.25 mm where the ring sits inside the wall
    (`jar_1p5L`) and 2.5 mm where it sits among the feet (`jar_1gal_155`); its weight holds it
    down, about 20 g net under water if printed solid, and nothing stops it turning or lifting. The
    bench says whether that is enough; the item below is what follows if not
  - `jar_1gal_180x197` and `jar_10L` do not build as airlifts: the tube stands where their baffles
    hang. Neither is registered
  - `jar_6p5gal` does not build as one: the equal-area gap stands its tube on 126 mm feet, 73 mm
    long in 325 mm of culture, and `draft_tube_span_min` (0.5 of the depth, a judgement) refuses
    it. Not registered

- [ ] **the annulus-sparged airlift (B), if the bench asks for it**
  - the tube as downcomer, the annulus as riser, bubbles up the lit wall. Wants a sparger outside
    the tube, which the mouth-limited ring cannot reach, and Chisti & Moo-Young 1987 recommend a
    cone under the turn for it (`docs/references.md`)

- [ ] **fix the draft tube, if standing it proves loose**
  - a plain lid leaves its centre free; a bayonet there, as the other ports carry what hangs from
    them, would locate the tube from above rather than by the ring's clearance
  - or shape each foot to capture the ring, so the ring holds the tube down and centred with no
    new part

- [ ] **the magnetic drive is modelled; what is left is the bench**
  - `drive_name = "magnetic"` builds it: a fan picked by rule in a carrier hung in the base bore,
    two magnets in a cap on its hub, a stir bar centred on the punt; the base is slotted for it
    under either drive, or the riser is where a build stands on one. `docs/build.md` has the
    assembly
  - nothing models the coupling. How much torque two 8 x 5 discs hand a 38 mm bar through 1 mm of
    air and 3-5 mm of glass, and at what fan speed the bar decouples, are measurements; the sizes are
    parameters so the answer can be put in. The target is the shaft drive's torque at equal tip
    speed, `v^2 D^3` scaled: 4.8-12.3 mN.m for the pair on `jar_1p5L`, 15.3-39.6 on `jar_1gal_155`
  - speed is PWM on the fan's own line and nothing reads it back; a 3-wire fan's tachometer line
    is the only encoder this drive has
  - centred, on the punt, was the decision: eccentric has nothing locating it on a floor whose high
    point is the centre it avoids, and Galletti finds it unsteady with power rising with eccentricity
  - the floor under the jar is sunk for the fan the bore admits, so a jar whose light happens to
    be short is not left without a drive. `jar_1p5L` is 3.77 mm deeper for it and gains a carrier;
    `jar_6p5gal` and `jar_1gal_155` want far more than `carrier_floor_lift_max` allows, so their
    magnetic builds stand on a riser instead (`docs/build.md`)

- [ ] **`jar_6p5gal` is not a floor problem and a deeper floor will not fix it**
  - a magnetic build of it now stands on a 35 mm riser and builds, coupling across the 13 mm
    below; it is not registered
  - its punt rises 15 mm at the magnets' radius and the carrier may not stand above the plane the
    jar lands on, so the hub cap grows 8 mm into the punt's void and the magnets reach 1 mm under
    the punt. Its 12 mm wall still puts them 13 mm from the culture, against 4-6 mm on every other
    jar
  - a 39 mm floor would seat a 120 x 25 at a 29 mm pitch, the best pitch of any jar, and it would
    still be coupling across those 13 mm
  - what would change it now is larger magnets, which is its own decision

## nice to haves

- [ ] a lead-in at the mouth of the bayonet tube bore, to ease the tube past the rod gland's o-ring
      without nicking it; the gland does the gripping now
- [ ] **back-plug the Atlas probe bore, or accept that the probe body is the seal**
  - the connector hex opens straight through to atmosphere (64 mm2); the probe body closes it by
    grip, not seal, and self-seals well enough on the bench. If a fix is ever wanted it is hot glue
    at the hex, not a modelled gland. Look at it with the sensor-gland item
- [ ] optional end styles (sensor gland) for atlas probes to match product more closely

## tooling / infrastructure / documentation

- [ ] **the DO probe's lean is capped by impellers a non-shaft build does not have**
  - `head_probe_tilt_ceiling()` reads `head_reach_obstacles()`, which lists both impellers under
    every drive; `head()` drops them from its own clearance report but not from the ceiling. Latent:
    every magnetic build reaches the full 4.5 deg today, and the airlift hangs DO straight without
    asking the ceiling. Safe either way, since the lean only comes out smaller
  - nothing reachable shows it: allowed 15 deg, `jar_10L` stops at 4.67 deg on its shaft and
    magnetic builds alike, with the impellers counted or not and even raised to 2.5 D, so
    something else binds first. Worth fixing when a build makes the impellers bind, with that
    build as the test

- [ ] **the port lettering is not pinned to a font, so it is whatever the host resolves `sans` to**
  - `scad/custom/bayonet_port.scad` asks for `font="sans"` in three places (:324, :332, :509).
    `sans` is a fontconfig alias, not a face, so the glyphs are whatever that host happens to
    prefer: here `fc-match sans` gives Noto Sans, with Liberation Sans also installed. The CI
    artifact's lettering was seen to differ from the bench's for exactly this reason
  - pinning it to one installed face makes the exported STL the same everywhere. It moves every
    port's mesh, so it wants its own commit
  - it is cosmetic - the lettering says which port is which - but a figure that changes with the
    machine is the kind of thing this project pins everywhere else

- [ ] **the probe port's transition lands exactly on the collet, and the obvious fix costs material**
  - `bayonet_probe_port`'s transition cone ends at exactly `-_transition_length`, which is exactly
    where the collet begins, at exactly the same diameter. Same defect as the three that are fixed,
    and on the leaning DO ports of several builds - five on this host - it leaves one or two
    near-degenerate triangles (two vertices 1e-5 apart) rather than a whole shared ring
  - carrying the cone on past the joint did clear it when measured, but it added 5.21 mm3, because
    the cone is solid out to the hex and the collet
    below it is not, so the lead lands as a 0.034 mm ledge across the collet's mouth where the
    probe body sits. Reverted for that reason
  - the direction that costs nothing is to carry the _collet_ up into the cone instead: the cone is
    wider there and solid, so the overlap adds no volume. That means reaching into
    `cylindrical_flex_collet`, whose body length also places its tabs, so it is not a one-liner
  - what is left is one or two triangles of zero volume in a closed mesh, and which side of the
    rounding they land on depends on the machine: the same part measures none here and one on the
    CI runner's CGAL. `export-parts` notes them and passes; it fails on a count that could only
    come from two solids sharing a face

- [ ] **where the tree breaks `docs/architecture.md`**
  - `head()` is one module in three sections - derived, checks and reports, geometry. The checks
    cannot become a module of their own without restating the derived values, since a module
    returns nothing; a split by subsystem is the next cut, and it is unsettled how the pieces
    share head.scad's parameters without reading each other
  - `custom/bayonet_interfaces.scad` includes `orings.scad` so rows can name their ring - rule 6
    allows it - and `bayonet_port.scad` then includes that file and receives every o-ring as a
    global. Recorded, not yet worth moving

- [ ] **the three stirred jars carry a second impeller the spacing does not support**
  - Fitschen eq. (5), `(H-d)/d > n > (H-2d)/(2d)`, in impeller diameters, on the jars that take the
    shaft drive (the two narrow jars build as airlift or magnetic):

    | vessel             | H_L    | d = 0.45 T | H_L/d | H/T   | band allows |
    | ------------------ | ------ | ---------- | ----- | ----- | ----------- |
    | jar_10L_220x305    | 229.50 | 94.50      | 2.429 | 1.093 | n = 1       |
    | jar_1gal_180x197   | 153.36 | 76.50      | 2.005 | 0.902 | n = 1       |
    | jar_6p5gal_305x470 | 325.26 | 126.36     | 2.574 | 1.158 | n = 1       |

  - it correlates with coverage: every jar the band puts at one impeller is spending coverage on
    the pair; `jar_1gal_180x197` at 0.107 D against the 0.5 D floor is the worst
  - no primary stands behind the rule, so `head()` reports and nothing asserts
  - the count stays two: the sparge ring sits in the gap, the power is per pair, the manifest lists
    two, and the reference build physically exists. Changing it unpicks all of that

- [ ] **the ring's bore is the departure, not its holes, and it is more than one designation**
  - on `jar_10L` given the ring (the stirred default is the arm), at its 4.11 L/min, sweeping the
    bore with 8 x 3 mm holes held:

    | bore        | feed velocity | open area | velocity head | verdict                             |
    | ----------- | ------------- | --------- | ------------- | ----------------------------------- |
    | 4.0 (today) | 5.46 m/s      | 4.50      | 17.9 Pa       | 2 departures                        |
    | 8.0         | 1.36          | 1.12      | 1.1           | 1 departure; pH tip hits the ring   |
    | 8.5         | 1.21          | 1.00      | 0.9           | clean sparger; pH tip hits the ring |
    | 10.0        | 0.87          | 0.72      | 0.5           | no room for a baffle                |

  - `sparge_bore()` is the riser's own OD, so the bore is a designation:
    `steel_tube_welded_10x0p5` is registered; there is no 8.5 row
  - what it costs is the cascade: the tube goes 6.4 -> 12.4 across the flats, and past 8 mm the
    wider ring meets the pH probe's tip and then leaves no room for a baffle; the riser's port
    bore, rod gland, pressure drop, support tube and BOM row all follow. Unpriced

- [ ] **`check-holes` still needs a CGAL render, so it stays outside `just check`**
  - both ends of every hole are probed - the arm's by default, the ring's with
    `-D head_sparger="ring"` - and it was proved by injection when written (a bore swept 180
    degrees failed 5 of 20 on `feed`). What would let it into the gate is a probe that needs no
    rendered mesh: the claim is geometric and the part is a union of primitives
  - `spoke_holes` is unprobed; no caller sets it and `sparger()` refuses the unbored-arm case

- [ ] **the sparger's two sockets are hard to tell apart**
  - both are 6.4 mm across the flats; the octagon's corners stand 0.264 mm proud of the round
    support. `docs/build.md` says count the facets. A print settles whether that is findable by
    hand; if not, a collar, a flat or a mark rather than a socket sized on its own

- [ ] **`check-scad`'s `-D '$fn=0'` pass is not the tessellation test it reads as**
  - a command-line `-D` crosses the `use` boundary on every version where an in-file assignment
    does not, so that pass also zeroes `sparger.scad`'s and the collet's own `$fn` - 48 and 64 in
    the CSG it renders, 96 and 128 in an exported part - and renders what no build renders. It
    still covers the crash a zero facet count causes
  - what would test divergence is rendering one part both ways at the CSG level
  - `OPENSCAD` is unset, so `just` runs whichever binary is first on PATH (2021.01 here, with a
    2026.09 nightly beside it). Worth pinning

- [ ] **the recess holds three quarters of the rubber, and it only matters on `jar_6p5gal`**
  - the recess is cut at `t(1-c)`, so `t*c` will not fit whatever the gasket. On a crown the
    displaced rubber flows into the width the contact chord never touches - on `jar_10L` 4.762 mm,
    about 0.857 mm2 against 1.890 free; on the one ground jar it must leave across the lands
  - `jar_6p5gal` also carries the registry's highest load, 1253.6 N per post and 7.34 MPa against
    398.8 and 2.92 on `jar_1gal_180`, the next highest. Reported, not asserted
  - the fix is a groove section 10-25 % over the gasket's; that jar offers 10 mm of rim where the
    gasket is held to 6. Not chased: it changes the lid for one jar

- [ ] **one printed part is on no print list, and bench furniture is in no account**
  - `support/bottle_holder.scad` is the only printed part among the bench furniture; the cart
    prints nothing, and the stand's `print_corner` is a printed substitute for a bought NopSCADlib
    bracket. The condensers, the humidifier cap and the pump mount are printed outside the
    manifests too, each from its own file. `check-parts` records all of them
  - the questions: does the reactor's print list cover an accessory, and is printing that bracket
    deliberate? The cart's extrusion, brackets and castors are on no purchase list either

- [ ] **designations for the pump and the inlet filter, if builds start to differ**
  - `head.scad` assigns hardware rows directly (`head_air_pump`, `sparge_inlet_filter`,
    `sparge_check_valve`, the clamp and the inserts among them) that no parameter set can change
  - the pump and the filter drive the gas budget, so they are the ones worth a `_name` designation
    first. Left until a build needs it

- [ ] **registry rows are read by position and not checked for shape**
  - `registry_by_name` checks the name only. A missing field shows as an undef warning, which
    `check-scad` fails on, but two fields of the same type swapped would pass
  - low risk; a row-length assert in each `_by_name` wrapper would close most of it

## long term / post paper submission

- [ ] adopt the Just the Docs OpenSCAD setup for this project, including its web-based preview

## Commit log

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2025-01-08 initial rebuild of CAD (as scad cuz better) since previous CAD assets are...well idk thats the issue
    [ImpellerPrint.stl, LidStencilModel.FCStd, LidStencilPrint.stl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]
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2025-01-26 fixed comments for customizer, turned probe mounts into a module and added to assembly
    [assembly.scad, probe_clamp.scad]
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2026-04-13 cut the flex tab short for better printing and support - also it does nothing as first half is the part in contact anyway
    [bayonette_probe_port.scad, bayonette_probe_port_15p9_a0p5_v2.stl, bayonette_probe_port_PC.3mf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]
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2026-04-19 fix: bayonet probe port takes proper transition length with minimum internal applied
    [bayonet_probe_port.scad]
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2026-04-24 fix: update api usage of bayonet lock and pass all params as args
    [bayonet_port.scad]
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2026-06-21 move peri pump mount params out temporaily and reintegrate lights to frame cleanly; fix circular_pattern.scad name from *_patterm.scad
    [circular_pattern.scad, frame.scad, peri_pump_frame_mount.scad]
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2026-06-22 refactor(scad-v2): drive vessel by opening diameter
    Make vessel_opening_diameter a primary coupling input and pass it to
    vessel() (mode B) instead of neck_corner_radius; the neck corner radius
    is now solved from the opening + upper corner radius. Drop the driven
    block that previously derived the opening. Geometry is unchanged (still
    220 - 2*(25+13.5) = 143).
    [assembly.scad]
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2026-06-23 refactor(scad-v2): namespace purchased registries as generic_<name>
    Rename each purchased registry's 'generic' instance to generic_dc_motor
    / generic_gearbox / generic_strip_light / generic_thermocouple_probe so
    they no longer collide when multiple registries are included together,
    and update consumers (frame, head). This also resolves dc_motors
    referencing the previously undefined generic_gearbox. Skips peri_pumps
    (WIP) and atlas (already named ph/do).
    [dc_motors.scad, frame.scad, gearboxes.scad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]
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2026-06-23 fix(scad-v2): remap head motor_mount call to the v2 module api
    The head copy-paste called motor_mount() with the old octagonal-design
    args, which the rewritten 3-part module ignored, leaving its required
    params undefined and cascading undef warnings. Rewrite the
    [Motor Mount Parameters] block and the call to the v2 signature and drop
    the obsolete octagonal params.
    [head.scad]
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2026-07-14 fix(scad-v2): reconcile bayonet port adapters with port api
    The probe and thermocouple ports still called bayonet_port() with the
    pre-1836614 signature (inner_radius, shell_thickness, oring_height,
    oring_interference), so interface_radius and neck_radius arrived undef
    and both adapters were dead. Convert them to the current vocabulary.
    That same commit also dropped shell_thickness from bayonet_port without
    passing it to the library, leaving the shell an accident of pin_radius*2,
    and deleted the o-ring groove while keeping the parameter. Re-expose
    shell_thickness and restore the groove, cut into the neck face at a depth
    of oring_cs_diameter less oring_interference, as v1 tube_lock did.
    Also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
    [bayonet_port.scad, bayonet_probe_port.scad, bayonet_thermocouple_port.scad]
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2026-08-01 chore(analysis): drop regenerable derived data
    Removes 62 MB of working-tree data that pipeline.py now rebuilds from
    raw/, plus the ad-hoc scripts it replaces.
    per_signal/ (29 files) verified byte-identical to the master split
    by device and signal, so the 2026 export was
    storing all 587,061 rows twice
    microalgae cleaned0/1/2 rebuilt and verified against recorded sha256
    spectroscopy splits rebuilt; the three per-condition files were
    hand-made copies with no script behind them
    spectroscopy_cleaned1 orphaned: written by clean_spectro.py and
    read by nothing
    The numbere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
    [dcmt0__estop.csv, dcmt0__mode.csv, dcmt0__motor1_brake.csv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]
2026-08-02 fix(scad-v2): register generic peri pump and parameterise the model
    peri_pumps.scad referenced a definition that was commented out, so
    `peri_pumps = [generic]` evaluated to [undef] and OpenSCAD warned on
    every load. It was the only registry of the seven that did not resolve.
    Registers generic_peri_pump in the same shape gearboxes.scad and
    dc_motors.scad use, and converts peri_pump.scad from twelve file-level
    globals to the accessor + registered-type pattern, with peri_pump(type)
    as the entry point. Roller count is now registered rather than baked in
    as [0:2] and i * 120.
    The old motor_diameter global fed exactly one expression,
    roller_carrier_diameter, so it was a pump dimension named afte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
    [peri_pump.scad, peri_pumps.scad]
2026-08-02 feat(scad-v2): register motors and gearbox by part number
    Replaces the generic motor and gearbox placeholders with the real parts
    and adds the second motor, so the two are no longer conflated.
    generic_dc_motor -> motor_36pg_3530_5p18 geared, drives the impeller
    generic_gearbox -> gearbox_36pg_5p18 36 mm planetary, 5.18:1
    motor_12v_5w bare, ships on the peri pump head
    The gearbox is named for itself rather than the motor it currently ships
    on, so the name still holds if it is repaired to another motor or
    dropped. Motors reference it; it knows nothing about them.
    Extends the dc_motor vector with a shaft boss and a face screw pattern.
    A motor drivi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
    [dc_motor.scad, dc_motors.scad, gearboxes.scad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]
2026-08-02 feat(scad-v2): mount the peri pump by its own motor
    The mount bored 34 mm for the geared impeller motor, which is not the
    motor that goes there. It now reads motor_12v_5w and bores 27.5.
    Drops the stale commented-out parameter block, which carried a drifted
    30 mm against the live 34 and named no parameters that exist in
    frame.scad.
    The flange screws stay literal: they bolt to the pump head faceplate,
    which is not modelled yet, so there is nothing to register them against.
    They are a different interface from the motor's own M2 face screws that
    fix it to the pump head.
    Adds an assert on flange span. The flange is only as wide as its screw
    pattern, so a wider motor cuts the bore clean throug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
    [peri_pump_frame_mount.scad]
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2026-08-03 refactor(scad-v2): drop bayonet port code the library owns
    bayonet_port re-derived two defaults that bayonet_lock.scad already
    computes identically: entry_depth (lib line 21) and shell_thickness
    (lib line 78). Both were passed on explicitly, which defeated the
    library's own defaults, and the shell_thickness branch was doubly
    dead since the accessor always returns a registered value. It also
    asserted part is "pin" or "lock", which the library asserts on half,
    and carried a verbatim copy of the library's _tube helper for a
    single call site.
    Pass entry_depth and shell_thickness straight through, keep only the
    o-ring assert that guards a silent failure (too little groove depth
    skips the seal wi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
    [bayonet_port.scad, bayonet_probe_port.scad, bayonet_thermocouple_port.scad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]
2026-08-03 refactor(scad-v2): register the bayonet interface as a type
    The interface vector was written out four times, and the copies had
    drifted: head.scad used a 10 mm interface radius with 1.2 mm pins
    while all three adapter previews used 9.5 mm with 1.5 mm pins, so
    opening any adapter previewed a port that could not mate with the
    one the lid actually builds.
    Move it to custom/bayonet_interfaces.scad as bayonet_std, following
    the purchased/dc_motors.scad pattern. The registry is pure data with
    no use of bayonet_port.scad, so bayonet_port can include it for its
    own preview without a cycle, and no consumer emits geometry just by
    including it.
    Regroup the row so each group is one concern: group 1 is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
    [bayonet_interfaces.scad, bayonet_port.scad, bayonet_probe_port.scad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]
2026-08-03 fix(scad-v2): seat the bayonet ports on the lid, not through it
    head.scad rebuilt the ports' mating datum by hand from bayonet_port's
    internals, and got it wrong three ways: the pin half is 15 mm tall
    against an 18 mm lid and had no shank, so it could never reach a lock
    below; the lock sat inside the lid's z range with 0.7 mm of radial
    interference over its full height; and the rotate([0,180,0]) used to
    flip the pin mapped theta to 180-theta, leaving the three pins 60 deg
    out of phase with the channels and buried in the lock shell.
    Give bayonet_port the datum instead: z = 0 is the panel's outer face,
    +z points outward, and both halves are emitted already mated. Add
    panel_thickness and the s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
    [bayonet_interfaces.scad, bayonet_port.scad, bayonet_probe_port.scad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]
2026-08-03 fix(scad-v2): open the center bore through the port flange
    The bore was cut inside the core cylinder's own difference, then the
    flange was unioned on top, capping it. Nine tube ports and the
    thermocouple had no through-hole, while the flange carried R and D
    labels advertising one. Only the probe ports escaped, because their
    hex connector cut passes through the flange anyway.
    Cut the bore against the finished body instead, which also drops the
    inner difference.
    Verified by intersecting each port with a 2.5 mm probe cylinder: the
    tube and thermocouple ports were solid over the flange's z = [0, 5]
    and are now empty. The probe port is unchanged, same vertex set.
    [bayonet_port.scad]
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2026-08-04 fix(scad-v2): make the render flags and parameters match what they do
    render_lights was declared but never read, so frame_lights() ran
    unconditionally: with every render flag false the frame still emitted
    1584 facets of strip lights. Gate it like its siblings.
    motor_mount's render_base_plate, render_middle_stand and render_face_plate
    were likewise never read; part_to_render is the live control, so drop the
    three that only looked like controls rather than adding a second mechanism.
    head's render_phdo_probes was never read either, and no pH/DO geometry
    exists in the head to gate.
    motor_faceplate_diameter was accepted by motor_mount() and never used.
    head passed gearbox_diameter() into it, w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
    [frame.scad, head.scad, motor_mount.scad]
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2026-08-04 fix(purchased): stop the probe registries emitting geometry
    Registry files are included for their data, so every other one keeps its
    example call commented out. atlas_probes and thermocouple_probes did not,
    and including the pair drew 11240 facets of stray probes into the consumer.
    This is not hypothetical: head.scad's own comment points at
    atlas_probes.scad as where the probe dimensions should come from, so acting
    on it would have scattered probes through the assembly.
    Also gave strip_lights the trailing newline it was missing.
    [atlas_probes.scad, strip_lights.scad, thermocouple_probes.scad]
2026-08-04 refactor(scad-v2): stop shadowing module parameters
    npt_thread_mount and cylindrical_flex_collet each reassigned one of their
    own parameters to hold its defaulted value, which reads as mutation in a
    language that has none. Give the resolved value its own name and default it
    with is_undef(), matching how the rest of the codebase tests for undef.
    [bayonet_thermocouple_port.scad]
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2026-08-04 docs(scad-v2): add the missing file headers and correct stale ones
    Six module files carried no @file header while every one of their peers
    did: bottle_holder, cylindrical_flex_collet, motor_mount,
    peri_pump_frame_mount, atlas_probe and thermocouple_probe. Registry files
    keep their plain // header, which is their own convention.
    thermocouple_probe's header described Atlas probe geometry, copy-pasted from
    atlas_probe.scad, and electronics_stand named itself with a hyphen it does
    not have. peri_pump_frame_mount labelled its flange placement "motor cut
    out", which is the cut made two lines below it.
    Added the customizer stop to bottle_holder, the one top-level file without
    it, and listed threa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
    [atlas_probe.scad, bottle_holder.scad, cylindrical_flex_collet.scad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]
2026-08-04 feat(purchased): register the replacement gearmotor and fix the bench one's name
    The bench motor is the 36GP-3530, but it was registered as "36PG-3530-5.18"
    with the letters transposed, which is also how it disagreed with
    docs/procurement.md. Renamed it and its gearbox to 36GP.
    Added motor_36pg_3429_5p2 and gearbox_36pg_3429_5p2 for the E-S Motor 36D
    (RobotShop RM-ESMO-16Q), which replaces it once the 36GP is unavailable.
    Body 34 x 29.4, gearbox 36 x 26.5, output shaft 8 x 20 D-cut, and from the
    vendor outline drawing a 4-M3 faceplate tapped 5 mm deep on a 28 mm bolt
    circle with a 22 mm pilot register.
    Two things the drawing gives that the schema cannot hold, so they are noted
    in the regis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
    [dc_motors.scad, gearboxes.scad, head.scad]
2026-08-04 chore(scad-v2): align z_fight and move the impeller note into TODO
    z_fight was 0.05 in head, frame and bottle_holder and 0.01 in the other
    nine; settled on 0.05. Every declaration is $preview-gated with a
    non-preview value of 0, so this moves preview only — confirmed by
    re-rendering two affected parts and comparing sorted vertex multisets
    against the pre-cleanup renders.
    Promoted the note buried at the top of head() about the impeller diameter
    needing a rethink and an assert, and recorded why frame and head still
    hardcode their vessel dimensions: that belongs to the interface pass, not
    to a piecemeal fix.
    [atlas_probe.scad, base.scad, bayonet_port.scad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]
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2026-08-04 fix(purchased): make a vessel render at its registered height
    The neck hangs off the outer rectangle rather than fitting inside it, so
    body_height has to give back what the neck adds. It was subtracting half
    the neck corner radius instead of all of it, never adding back the wall
    that the neck flat is offset by, and subtracting rim_rad even though the
    rim arc is centred on the flat and so adds no height.
    Every jar rendered off by exactly neck_corner_radius / 2 - thickness -
    rim_rad, with no residual: 6.5 gal was +4.95 and 1.5 L was -2.32. All
    six registered vessels now render at their registered height, diameter
    and bore.
    Carried over unchanged from scad/jar.scad:27, so it predates the rewr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
    [vessel.scad]
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2026-08-05 fix: add allowance to motor mount to allow boss to seat w/out interferenece
    [motor_mount.scad]
2026-08-05 chore(bayo-probes): tighten bayonet flange to min thats reasonable (still covers oring and a bit)
    [bayonet_interfaces.scad]
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2026-08-05 feat(thermocouples): add 6 inch variation of thermocouple to use in shorter vessels
    [thermocouple_probes.scad]
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2026-08-05 fix(bayonet_port): widen the o-ring land to seat a 1.6 mm cross section
    The rebate ran from a spigot radius derived from the panel hole, leaving
    a 1.2 mm land on bayonet_std - narrower than the 1.6 mm o-ring cross
    section it has to seat. Run it from the interface radius less the
    allowance instead, which gives 3.6 mm, and drop the now-unused
    _spigot_radius.
    [bayonet_port.scad]
2026-08-05 fix(head): cut each probe port for its registered probe
    head_ports gains a third slot naming the atlas probe each probe port is
    built for, and bayonet_probe_port reads the body diameter from that
    registration instead of taking a loose parameter. Both ports were cut at
    a shared 15.9; they are now 15.6 for pH and 16.0 for DO.
    Also drops the hardcoded 10 L jar dimensions from head.scad's standalone
    preview in favour of the registered vessel's accessors.
    [assembly.scad, bayonet_probe_port.scad, head.scad]
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2026-08-05 fix(bayo-tc): remove unneeded allowance from lower diameter that only added a false lip feature at the transition
    [bayonet_thermocouple_port.scad]
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2026-08-09 feat(probes): register the four pH grades from atlas datasheets
    The pH line is mini, consumer, lab and research. All four share one cap
    and differ only in the shaft below it, so the port geometry is identical
    across them - only the engraved mark changes. Each row carries its
    product page and datasheet PDF.
    Cap diameter and height stay the caliper readings of the lab-grade unit
    on hand, applied to all four rows since the cap is common; the sheets
    give a nominal 16 x 36.2, which corroborates them to within 0.4 mm. The
    collet grips that surface and 0.4 mm is most of the flex tab's 0.5 mm
    deflection, so the measurement wins. Shaft length and diameter and the
    cable diameter come from the sheets.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
    [atlas_probes.scad, bayonet_probe_port.scad, head.scad]
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2026-08-09 docs(probes): record what 16.3 is and which numbers are safe to cut from
    body_d is the only registered field that reaches printed geometry, and
    the EC and ORP rows are datasheet nominal where pH and DO are caliper.
    The pH cap measured 15.6 against a nominal 16.0, and 0.4 mm is most of
    the flex tab's 0.5 mm deflection, so say plainly that an uncalipered row
    should be measured before a port is printed from it.
    16.3 in the collet's preview block is the hard-backed probe variant.
    TODO.md records that, but 15.9 soft-backed is gone from the tree and
    16.3 had become a bare number with its meaning one file away - close to
    being tidied away as a stale duplicate. It now names itself.
    [atlas_probes.scad, cylindrical_flex_collet.scad]
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2026-08-09 chore: remove the v1 scad tree
    Superseded by scad-v2 and broken against the current libraries anyway -
    tube_lock and thermocouple_lock call outer_bayonet(), which
    bayonet-lock-scad dropped at 0.6.0.
    Swept every file for anything not carried forward. All seventeen have a
    v2 counterpart, most renamed: jar to vessel, dcmotor to dc_motor,
    probe_atlas to atlas_probe, peri_pump_side_mount to
    peri_pump_frame_mount with identical values, tube_lock and
    thermocouple_lock to the bayonet ports. _config.scad was two lines both
    inlined per file.
    Three things are not represented anywhere, all superseded rather than
    lost: circular_pattern and surround_lights, replaced by frame.scad's
    quadrant placement, w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
    [_config.scad, assembly.scad, base.scad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]
2026-08-09 fix(probes): stop atlas_probes.scad emitting probe geometry again
    Two example lines in the usage block were left uncommented, and the
    file is include'd by head.scad and bayonet_probe_port.scad, so both
    probes were being drawn at the origin of every consumer. head.scad's
    normalized CSG had gone from 577 to 591 elements.
    This is the regression 1a6df3d fixed once already, so the comment now
    says why the block has to stay commented rather than just labelling it
    example usage. Checked the other registries; all are data-only.
    [atlas_probes.scad]
2026-08-09 chore: rename scad-v2 to scad
    The v1 tree is gone as of 376c21f, so the qualifier no longer
    distinguishes anything. Every include in the tree is relative, and the
    only path reference outside it was the README structure section, which
    now describes one source tree and points at the commit holding the old
    one.
    [arc_points.scad, assembly.scad, atlas_probe.scad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]
2026-08-09 feat(lights): register the four strip lights as products
    The single generic row held RWNTAO measurements under a generic name.
    It is now a proper product with its specs and link, alongside three new
    bars, and generic_strip_light drops back to being the format
    placeholder the way atlas_probe is.
    frame.scad selects one via frame_light rather than naming the row in
    five places, so the base can be pocketed for a different bar by
    changing one line.
    RWNTAO length corrected 336 to 330 to match the measurement the CSV
    already carried, and the CSV note updated to agree. This moves no
    geometry: the light cutout is a through-slot spanning z=0 to length and
    every part it passes lies below z=318, so an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
    [frame.scad, purchased-parts.csv, strip_lights.scad]
2026-08-09 fix(probes): describe each probe feature once, from its datasheet
    The tail group added earlier held no probe facts. Tracing the geometry:
    tail_maj_d was inert - 8.7 to 6 and 8.7 to 9.1 both render an identical
    part, because the port's hex cut is 9.18 across flats and removes
    strictly more - and it duplicated neck, which already described the same
    strain relief boot. tail_min_d and tail_h size the collet's neck
    section, which houses that boot, so they were never independent of it.
    conn_d was not the connector at all but the hex circumdiameter that
    happens to clear one.
    So the row is now one group per physical feature: neck the boot, body
    the cap, tip the shaft, conn_d the connector, and the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
    [atlas_probe.scad, atlas_probes.scad, bayonet_probe_port.scad]
2026-08-09 fix(probes): put every cap on its datasheet value and split the allowance
    The pH and DO caps were the last rows carrying caliper readings, 15.6
    and 16.0 diameters over 36.0 and 35.6 heights, where all six of those
    sheets say 16.0 x 36.2. Every row is now the product as its datasheet
    describes it, with no exceptions left, and the header says so plainly.
    The port moves with it: 9556 to 9100 facets, bore 0.4 wider and grip
    0.2 longer.
    That only works if the consuming part can compensate, and one
    collet_internal_allowance was doing two unrelated jobs - the cap grip
    clearance and the connector hex clearance - so tuning a tight cap would
    have silently resized the connector hole with it. Split int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
    [atlas_probes.scad, bayonet_probe_port.scad, head.scad]
2026-08-09 chore(probes): stop tracking the hard-backed variant
    No datasheet mentions a backing variant, so there is nothing to
    register and nothing to reconcile against. The comment on 16.3 in
    cylindrical_flex_collet.scad goes, leaving that file exactly as it was
    before 72ff461 - it is a generic module and its preview values are just
    example hardware.
    TODO records the decision rather than the loose end. If a backing
    variant turns out to be a real product it gets its own registered row.
    [cylindrical_flex_collet.scad]
2026-08-09 feat(probes): split the lab pH and DO probes into g1 and g2
    Atlas sells two generations of the lab grade pH and DO probes. g2 is the
    current product and what the linked sheets describe; g1 is no longer
    sold as of 2026-08 but is still in use here, so both are registered and
    every consumer names g2 explicitly.
    The pH rows also change how the 36.2 mm cap is split. It is now body
    30.2 plus neck 6, from measurement, rather than the whole 36.2 sitting
    in body with neck as a separate 26 mm boot above it. That shortens the
    collet's grip by 6 mm and its neck section by 20 mm, so the printed
    port moves with it.
    g1 keeps the older decomposition, which is what it physically is - a
    long visible boot ov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
    [atlas_probes.scad, bayonet_probe_port.scad, head.scad]
2026-08-10 feat(frame): size the base floor and wall from the light and rod
    The base floor was a fixed 3 mm, so a light longer than the vessel had
    nowhere to sit and the wall thickness was derived from the light depth
    alone with nothing checking it against the rod.
    Take lights_length, wall_thickness and rod_length as arguments. Derive
    base_floor_height from how far the light overruns the vessel, and assert
    the wall clears both the light pocket and the rod hole. total_height now
    means the frame's own height rather than including the top base, and
    lower_base_height is derived from the wall height plus the floor.
    The rod and its nuts move up with the floor; the mid-span nut is dropped
    since the lower ba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
    [assembly.scad, frame.scad]
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
